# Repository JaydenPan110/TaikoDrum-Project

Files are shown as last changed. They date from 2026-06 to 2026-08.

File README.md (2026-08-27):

# Arduino Slot Machine

616CD408-CAEE-421D-8965-62FF21B37599_L0_001-2026-06-23, 9_50_43 AM

An interactive, hardware-driven slot machine featuring three physical reels, automated coin detection, a joystick lever mechanism, and a custom payout dispenser. 

---

## Project Overview

This project is a physical, interactive slot machine powered by dual Arduino microcontrollers. The system replicates a classic casino game loop using automated mechanical and electronic components:

1. **Coin Insertion:** The user inserts a coin into the slot to arm the machine.
2. **The Spin:** Pulling the joystick down triggers three independent reels to spin. 
3. **The Stop:** Each motor sequentially self-adjusts to display a specific symbol to the user.
4. **The Payout:** If all three wheels align on the same symbol, a jackpot is triggered, activating a specialized servo-driven dispensing mechanism for a physical payout.

---

## Component List

| Category | Item | Quantity |
| :--- | :--- | :--- |
| **Microcontrollers & Shields** | Arduino UNO | 2 |
| | CNC Shield | 1 |
| **Actuators & Motors** | Nema 17 Stepper Motor | 3 |
| | Servo Motor | 1 |
| **Sensors & Inputs** | Analog Joystick | 1 |
| | Photoresistor (LDR) | 1 |
| | Infrared (IR) Receiver | 1 |
| | Infrared (IR) Remote | 1 |
| **Display & Audio** | Freenove 8 RGB LED Ring | 1 |
| | RGB LED | 1 |
| | Passive Buzzer | 1 |
| **Power & Cabling** | 12V 5A AC to DC Power Converter | 1 |
| | USB Cable | 1 |
| | Jumper Wires (M/M & M/F) | Assortment |
| **Discrete Components** | Resistors (220Ω, 1kΩ, 10kΩ) | Various |
| **Hardware & Enclosure** | 3D Printed Components (Reels/Gears) | Custom |
| | M2.5 Screws and Nuts | 12 |
| | Wood Support Brackets & Housing | Custom |

## Schematic Pictures ( might be a bit outdated ) 




## Project Evolution & Changelog

The design of this slot machine evolved significantly during prototyping to adapt to structural requirements and improve user experience:

### Input Mechanism: From Push-Button to Joystick
* **Original Plan:** A simple arcade button to trigger the spin sequence after coin validation.
* **Revision:** Replaced the button and its status LED with an analog joystick. Pulling the joystick down provides a more tactile, satisfying "slot machine lever" feel.

### Coin Detection: From Optical Interruption to Contact Sensing
* **Original Plan:** A break-beam sensor configuration where a falling coin temporarily blocked an LED shining on a detector.
* **Revision:** Simplified to a direct-contact photoresistor setup inside the coin chute. Integrated a passive buzzer audio cue to sound a confirmation tone immediately upon reliable detection.

### Enclosure Design: From Cardboard to Reinforced Wood
* **Original Plan:** A fully 3D-printed enclosure or light cardboard housing.
* **Revision:** 3D printing the entire structural shell proved too time-consuming, while cardboard lacked the structural integrity to support the torque and weight of three Nema 17 stepper motors. The structural framing was redesigned using wood, successfully neutralizing motor vibrations and improving overall system durability.

credit to [WhiteStudio](https://makerworld.com/en/models/1272917-nanoslot-modular-arduino-based-slot-machine-w-rtp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) for CAD models

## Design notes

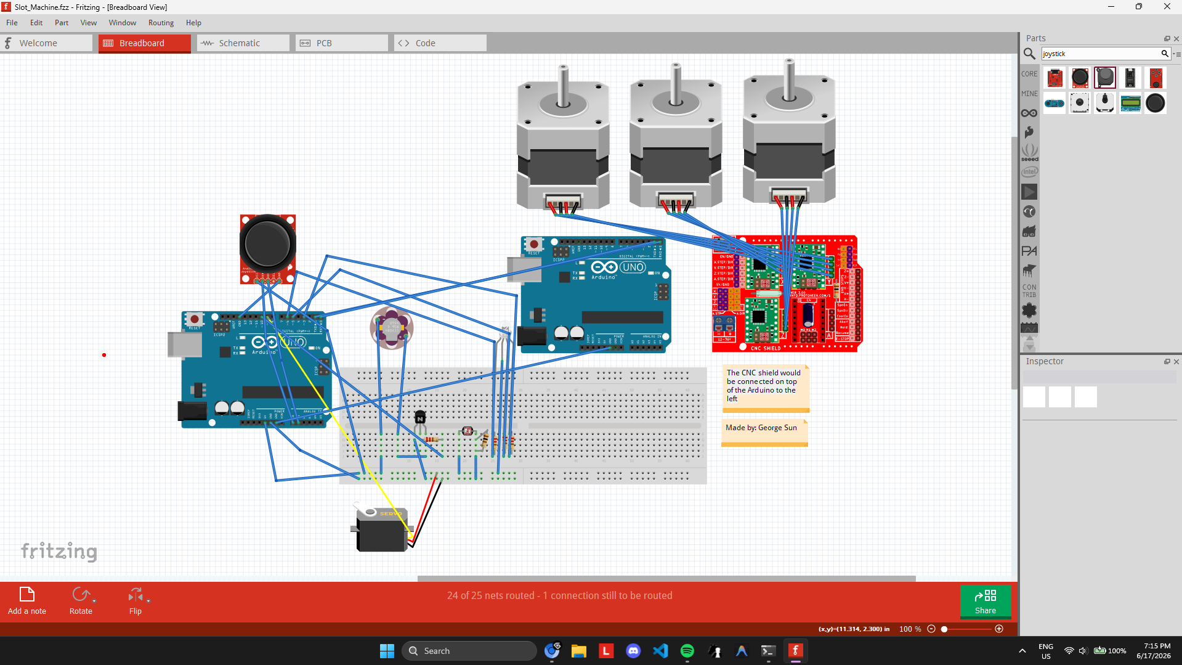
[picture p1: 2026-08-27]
PCB/Screenshot 2026-06-17 191529.png

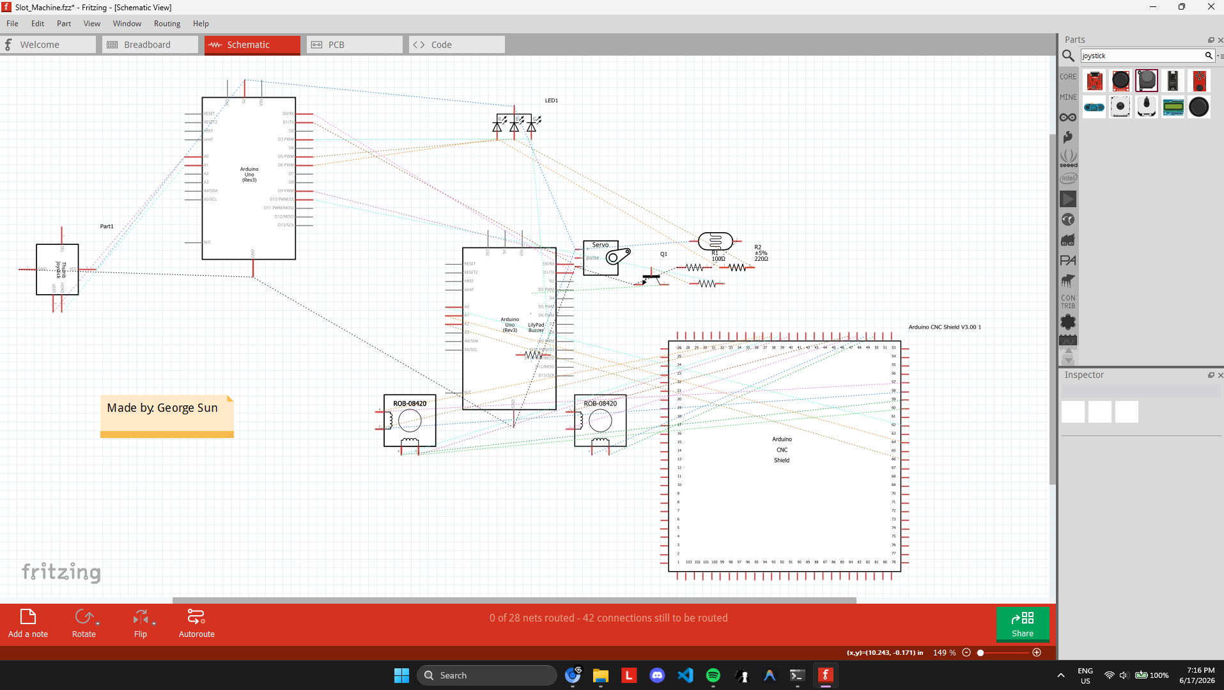
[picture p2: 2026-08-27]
PCB/Screenshot 2026-06-17 191656.png

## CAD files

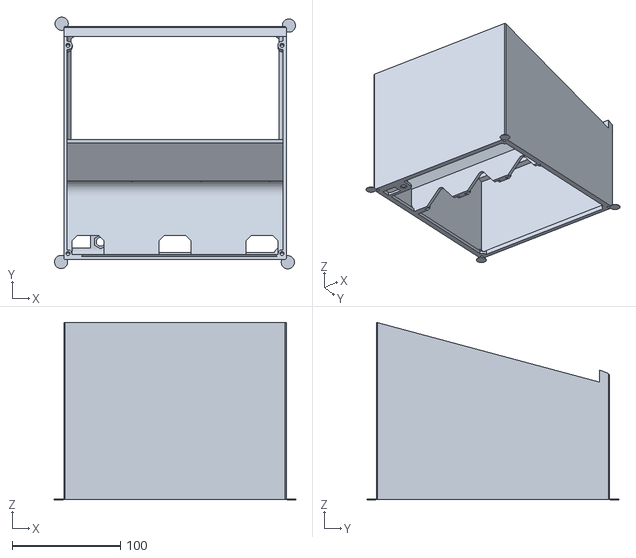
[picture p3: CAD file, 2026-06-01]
CAD/obj_8_Main body small.stl
222.7 x 232.6 x 163.9

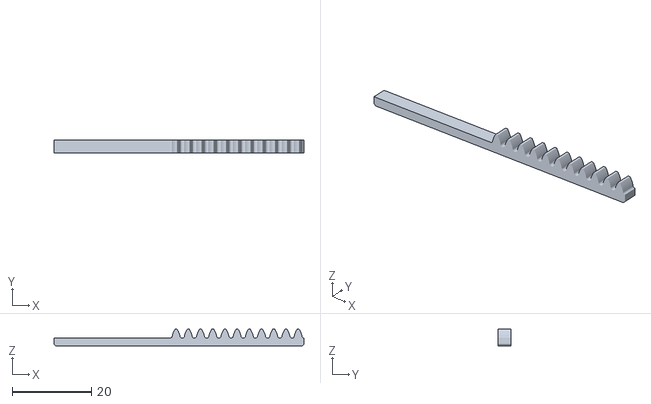
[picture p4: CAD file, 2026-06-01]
CAD/obj_6_Rack small.stl
63.0 x 3.23 x 4.17

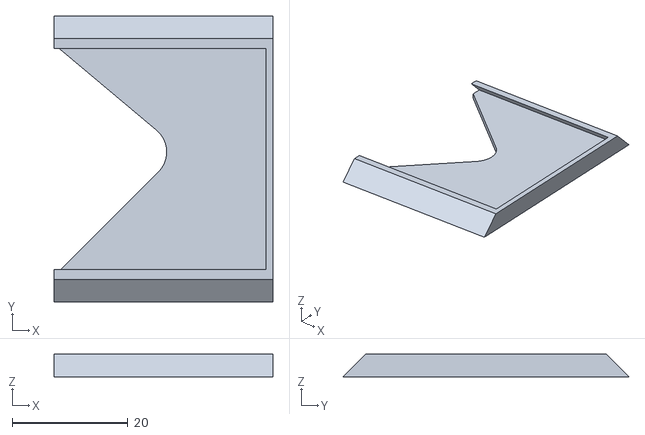
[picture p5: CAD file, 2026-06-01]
CAD/obj_7_Hold in place small.stl
37.7 x 49.4 x 3.92

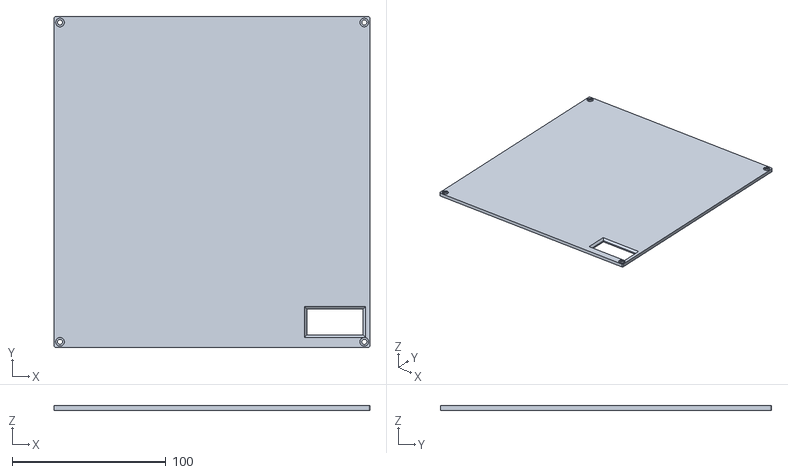
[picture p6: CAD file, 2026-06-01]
CAD/obj_3_Back plate small.stl
205.6 x 215.4 x 2.94

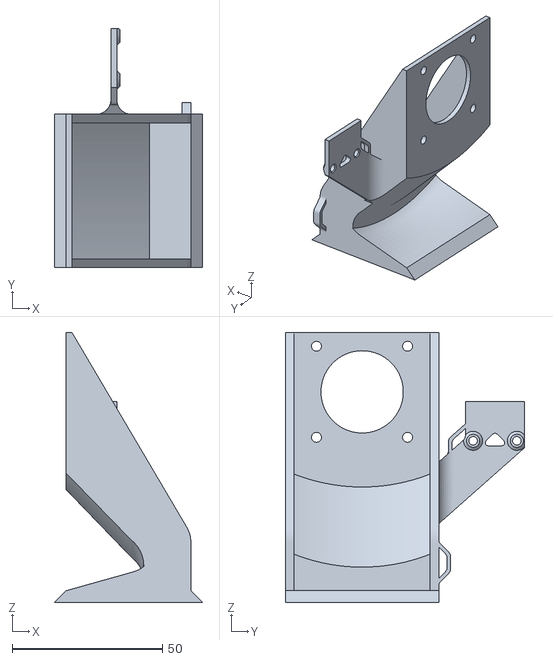
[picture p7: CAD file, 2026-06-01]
CAD/obj_1_Bracket new small.stl
49.4 x 79.7 x 89.9

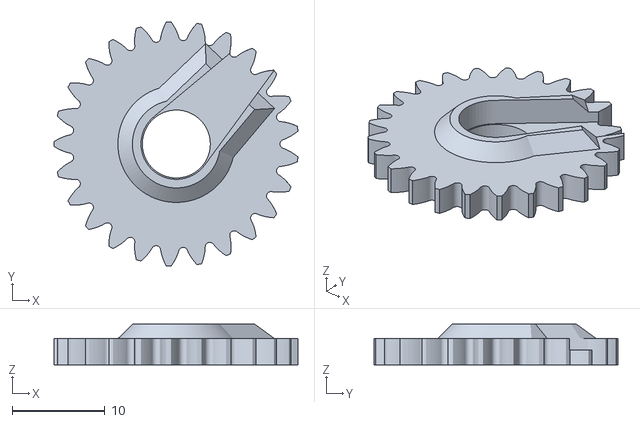
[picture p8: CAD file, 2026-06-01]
CAD/obj_4_Pinion small.stl
26.4 x 26.4 x 4.41

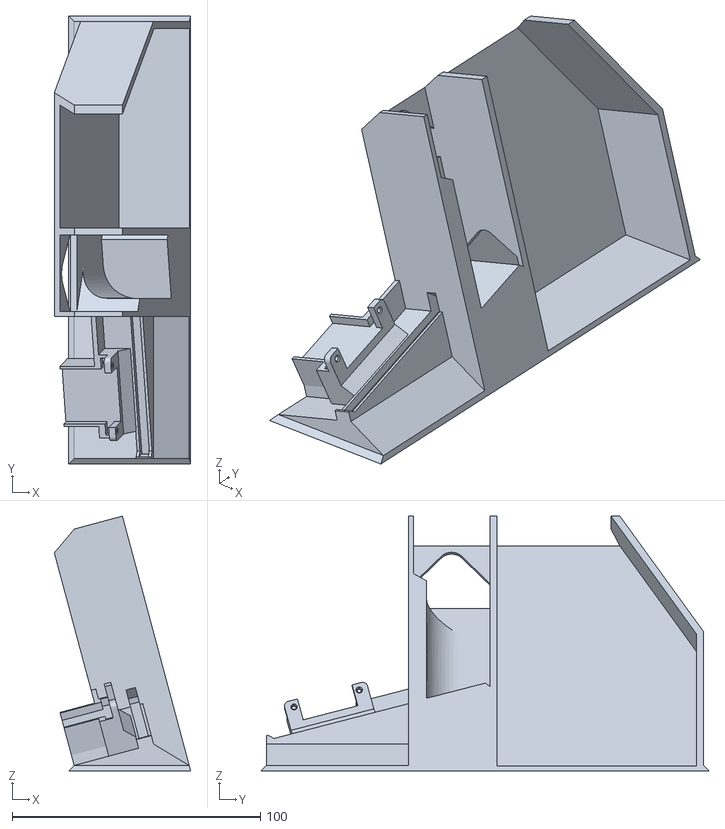
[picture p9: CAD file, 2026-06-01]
CAD/obj_2_Coin dispenser body small.stl
55.0 x 180.6 x 102.7

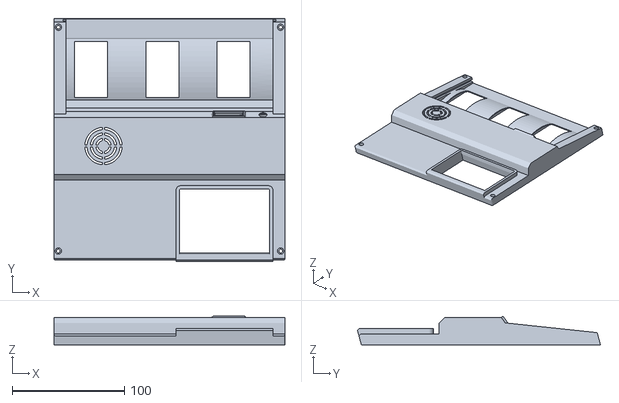
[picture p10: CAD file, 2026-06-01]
CAD/obj_9_cabinet front panel small.stl
205.6 x 216.3 x 25.6

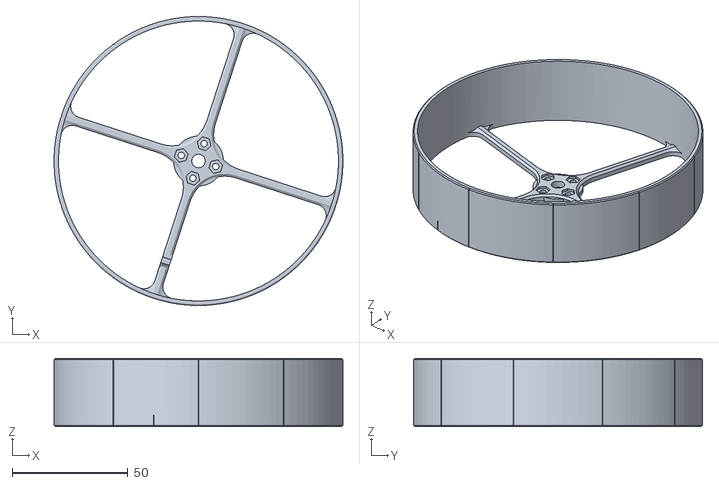
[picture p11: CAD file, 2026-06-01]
CAD/obj_5_Reel small.stl
124.6 x 124.6 x 29.4

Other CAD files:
CAD/obj_8_Main body.step
CAD/obj_3_Back plate.step
CAD/obj_2_Coin dispenser body.step
CAD/obj_6_Rack.step
CAD/obj_7_Hold in place.step
CAD/obj_1_Bracket new.step
CAD/obj_5_Reel.step
CAD/obj_4_Pinion.step
CAD/obj_9_cabinet front panel.step

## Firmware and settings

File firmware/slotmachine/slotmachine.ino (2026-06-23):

#include <pitches.h>
#include <Servo.h>
#include <IRremote.hpp>
#include <Adafruit_NeoPixel.h>
#include <AccelStepper.h>

enum Symbol {
  SYM_CHERRY,
  SYM_SEVEN,
  SYM_LIMON,
  SYM_BAR,
  SYM_MANDERIN,
  SYM_WATERMELON,
  SYM_BELL,
  SYM_BAR2,
  SYM_BANANA,
  SYM_GRAPE
};

const String SYMBOL_NAMES[] = {
  "CHERRY",
  "Seven",
  "LIMON",
  "BAR",
  "MANDERIN",
  "WATERMELON",
  "BELL",
  "BAR2",
  "BANANA",
  "GRAPE"
};

static const int PHYS_TO_LOG[10] = {6, 7, 8, 9, 0, 1, 2, 3, 4, 5};

int getSymbol(long position) {
  return PHYS_TO_LOG[((position + 80) % 200) / 20];
}

#define IR_RECEIVE_PIN 12
#define IR_PLAY_BUTTON 0xEA15FF00

#define LDR_PIN A0
#define BUZZER_PIN 10
#define BUTTON_PIN 2

#define LED_R 6
#define LED_G 5
#define LED_B 3

const int servoPin = 9;
#define NEO_PIN 11
#define NUM_LEDS 8

Adafruit_NeoPixel strip(NUM_LEDS, NEO_PIN, NEO_GRB + NEO_KHZ800);

#define STEP_X A2
#define STEP_Y A3
#define STEP_Z A4
#define DIR_PIN A5

#define SPIN_TARGET 50000

AccelStepper stepperX(AccelStepper::DRIVER, STEP_X, DIR_PIN);
AccelStepper stepperY(AccelStepper::DRIVER, STEP_Y, DIR_PIN);
AccelStepper stepperZ(AccelStepper::DRIVER, STEP_Z, DIR_PIN);

Servo coinServo;

int melody[] = {
  NOTE_E5, NOTE_E5, REST, NOTE_E5, REST, NOTE_C5, NOTE_E5,
  NOTE_G5, REST, NOTE_G4, REST, 
  NOTE_C5, NOTE_G4, REST, NOTE_E4,
  NOTE_A4, NOTE_B4, NOTE_AS4, NOTE_A4,
  NOTE_G4, NOTE_E5, NOTE_G5, NOTE_A5, NOTE_F5, NOTE_G5,
  REST, NOTE_E5,NOTE_C5, NOTE_D5, NOTE_B4,
  NOTE_C5, NOTE_G4, REST, NOTE_E4,
  NOTE_A4, NOTE_B4, NOTE_AS4, NOTE_A4,
  NOTE_G4, NOTE_E5, NOTE_G5, NOTE_A5, NOTE_F5, NOTE_G5,
  REST, NOTE_E5,NOTE_C5, NOTE_D5, NOTE_B4,
  
  REST, NOTE_G5, NOTE_FS5, NOTE_F5, NOTE_DS5, NOTE_E5,
  REST, NOTE_GS4, NOTE_A4, NOTE_C4, REST, NOTE_A4, NOTE_C5, NOTE_D5,
  REST, NOTE_DS5, REST, NOTE_D5,
  NOTE_C5, REST,
  
  REST, NOTE_G5, NOTE_FS5, NOTE_F5, NOTE_DS5, NOTE_E5,
  REST, NOTE_GS4, NOTE_A4, NOTE_C4, REST, NOTE_A4, NOTE_C5, NOTE_D5,
  REST, NOTE_DS5, REST, NOTE_D5,
  NOTE_C5, REST,
  
  NOTE_C5, NOTE_C5, NOTE_C5, REST, NOTE_C5, NOTE_D5,
  NOTE_E5, NOTE_C5, NOTE_A4, NOTE_G4,
  
  NOTE_C5, NOTE_C5, NOTE_C5, REST, NOTE_C5, NOTE_D5, NOTE_E5,
  REST, 
  NOTE_C5, NOTE_C5, NOTE_C5, REST, NOTE_C5, NOTE_D5,
  NOTE_E5, NOTE_C5, NOTE_A4, NOTE_G4,
  NOTE_E5, NOTE_E5, REST, NOTE_E5, REST, NOTE_C5, NOTE_E5,
  NOTE_G5, REST, NOTE_G4, REST, 
  NOTE_C5, NOTE_G4, REST, NOTE_E4,
  
  NOTE_A4, NOTE_B4, NOTE_AS4, NOTE_A4,
  NOTE_G4, NOTE_E5, NOTE_G5, NOTE_A5, NOTE_F5, NOTE_G5,
  REST, NOTE_E5, NOTE_C5, NOTE_D5, NOTE_B4,
  
  NOTE_C5, NOTE_G4, REST, NOTE_E4,
  NOTE_A4, NOTE_B4, NOTE_AS4, NOTE_A4,
  NOTE_G4, NOTE_E5, NOTE_G5, NOTE_A5, NOTE_F5, NOTE_G5,
  REST, NOTE_E5, NOTE_C5, NOTE_D5, NOTE_B4,
  
  NOTE_E5, NOTE_C5, NOTE_G4, REST, NOTE_GS4,
  NOTE_A4, NOTE_F5, NOTE_F5, NOTE_A4,
  NOTE_D5, NOTE_A5, NOTE_A5, NOTE_A5, NOTE_G5, NOTE_F5,
  
  NOTE_E5, NOTE_C5, NOTE_A4, NOTE_G4,
  NOTE_E5, NOTE_C5, NOTE_G4, REST, NOTE_GS4,
  NOTE_A4, NOTE_F5, NOTE_F5, NOTE_A4,
  NOTE_B4, NOTE_F5, NOTE_F5, NOTE_F5, NOTE_E5, NOTE_D5,
  NOTE_C5, NOTE_E4, NOTE_E4, NOTE_C4,
  
  NOTE_E5, NOTE_C5, NOTE_G4, REST, NOTE_GS4,
  NOTE_A4, NOTE_F5, NOTE_F5, NOTE_A4,
  NOTE_D5, NOTE_A5, NOTE_A5, NOTE_A5, NOTE_G5, NOTE_F5,
  
  NOTE_E5, NOTE_C5, NOTE_A4, NOTE_G4,
  NOTE_E5, NOTE_C5, NOTE_G4, REST, NOTE_GS4,
  NOTE_A4, NOTE_F5, NOTE_F5, NOTE_A4,
  NOTE_B4, NOTE_F5, NOTE_F5, NOTE_F5, NOTE_E5, NOTE_D5,
  NOTE_C5, NOTE_E4, NOTE_E4, NOTE_C4,
  NOTE_C5, NOTE_C5, NOTE_C5, REST, NOTE_C5, NOTE_D5, NOTE_E5,
  REST,
  
  NOTE_C5, NOTE_C5, NOTE_C5, REST, NOTE_C5, NOTE_D5,
  NOTE_E5, NOTE_C5, NOTE_A4, NOTE_G4,
  NOTE_E5, NOTE_E5, REST, NOTE_E5, REST, NOTE_C5, NOTE_E5,
  NOTE_G5, REST, NOTE_G4, REST, 
  NOTE_E5, NOTE_C5, NOTE_G4, REST, NOTE_GS4,
  NOTE_A4, NOTE_F5, NOTE_F5, NOTE_A4,
  NOTE_D5, NOTE_A5, NOTE_A5, NOTE_A5, NOTE_G5, NOTE_F5,
  
  NOTE_E5, NOTE_C5, NOTE_A4, NOTE_G4,
  NOTE_E5, NOTE_C5, NOTE_G4, REST, NOTE_GS4,
  NOTE_A4, NOTE_F5, NOTE_F5, NOTE_A4,
  NOTE_B4, NOTE_F5, NOTE_F5, NOTE_F5, NOTE_E5, NOTE_D5,
  NOTE_C5, NOTE_E4, NOTE_E4, NOTE_C4,
  
  // Game over sound
  NOTE_C5, NOTE_G4, NOTE_E4,
  NOTE_A4, NOTE_B4, NOTE_A4, NOTE_GS4, NOTE_AS4, NOTE_GS4,
  NOTE_G4, NOTE_D4, NOTE_E4
};

int durations[] = {
  8, 8, 8, 8, 8, 8, 8,
  4, 4, 8, 4, 
  4, 8, 4, 4,
  4, 4, 8, 4,
  8, 8, 8, 4, 8, 8,
  8, 4,8, 8, 4,
  4, 8, 4, 4,
  4, 4, 8, 4,
  8, 8, 8, 4, 8, 8,
  8, 4,8, 8, 4,
  
  
  4, 8, 8, 8, 4, 8,
  8, 8, 8, 8, 8, 8, 8, 8,
  4, 4, 8, 4,
  2, 2,
  
  4, 8, 8, 8, 4, 8,
  8, 8, 8, 8, 8, 8, 8, 8,
  4, 4, 8, 4,
  2, 2,
  
  8, 4, 8, 8, 8, 4,
  8, 4, 8, 2,
  
  8, 4, 8, 8, 8, 8, 8,
  1, 
  8, 4, 8, 8, 8, 4,
  8, 4, 8, 2,
  8, 8, 8, 8, 8, 8, 4,
  4, 4, 4, 4, 
  4, 8, 4, 4,
  
  4, 4, 8, 4,
  8, 8, 8, 4, 8, 8,
  8, 4, 8, 8, 4,
  
  4, 8, 4, 4,
  4, 4, 8, 4,
  8, 8, 8, 4, 8, 8,
  8, 4, 8, 8, 4,
  
  8, 4, 8, 4, 4,
  8, 4, 8, 2,
  8, 8, 8, 8, 8, 8,
  
  8, 4, 8, 2,
  8, 4, 8, 4, 4,
  8, 4, 8, 2,
  8, 4, 8, 8, 8, 8,
  8, 4, 8, 2,
  
  8, 4, 8, 4, 4,
  8, 4, 8, 2,
  8, 8, 8, 8, 8, 8,
  
  8, 4, 8, 2,
  8, 4, 8, 4, 4,
  8, 4, 8, 2,
  8, 4, 8, 8, 8, 8,
  8, 4, 8, 2,
  8, 4, 8, 8, 8, 8, 8,
  1,
  
  8, 4, 8, 8, 8, 4,
  8, 4, 8, 2,
  8, 8, 8, 8, 8, 8, 4,
  4, 4, 4, 4, 
  8, 4, 8, 4, 4,
  8, 4, 8, 2,
  8, 8, 8, 8, 8, 8,
  
  8, 4, 8, 2,
  8, 4, 8, 4, 4,
  8, 4, 8, 2,
  8, 4, 8, 8, 8, 8,
  8, 4, 8, 2,
  
  //game over sound
  4, 4, 4,
  8, 8, 8, 8, 8, 8,
  8, 8, 2
};

int coinMelody[] = {
  NOTE_C4, REST, NOTE_G4, REST, NOTE_AS4, NOTE_C5, NOTE_AS4, REST, NOTE_F4, NOTE_DS4, REST,
  NOTE_C4, REST, NOTE_G4, REST, NOTE_AS4, NOTE_C5, NOTE_AS4, REST, NOTE_F4, NOTE_DS4, REST,
  NOTE_C4, REST, NOTE_G4, REST, NOTE_AS4, NOTE_C5, NOTE_AS4, REST, NOTE_F4, NOTE_DS4, REST,

  NOTE_C4, REST, NOTE_E4, REST, NOTE_G4, NOTE_A4, NOTE_AS4,
  NOTE_C5, REST, NOTE_C5, REST, NOTE_AS4, REST, NOTE_A4, REST,
  NOTE_AS4, REST, NOTE_AS4, NOTE_C5, REST, NOTE_AS4, NOTE_A4, REST,
  REST,
  NOTE_C5, REST, NOTE_AS4, REST, NOTE_A4, REST, NOTE_AS4, REST, NOTE_E5,
  REST,

  NOTE_C5, REST, NOTE_C5, REST, NOTE_AS4, REST, NOTE_A4, REST,
  NOTE_AS4, REST, NOTE_AS4, NOTE_C5, REST, NOTE_AS4, NOTE_A4, REST,
  REST,
  NOTE_C5, REST, NOTE_AS4, REST, NOTE_A4, REST, NOTE_AS4, REST, NOTE_E4,
  REST,
};

int coinDurations[] = {
  4, 8, 4, 8, 4, 8, 8, 16, 8, 8, 16,
  4, 8, 4, 8, 4, 8, 8, 16, 8, 8, 16,
  4, 8, 4, 8, 4, 8, 8, 16, 8, 8, 16,

  4, 8, 4, 8, 4, 4, 4,
  8, 16, 8, 16, 8, 16, 8, 16,
  8, 16, 8, 8, 16, 8, 8, 16,
  4,
  8, 16, 8, 16, 8, 16, 8, 4, 8,
  4,

  8, 16, 8, 16, 8, 16, 8, 16,
  8, 16, 8, 8, 16, 8, 8, 16,
  4,
  8, 16, 8, 16, 8, 16, 8, 4, 8,
  1
};

int spinMelody[] = {
  NOTE_E5, NOTE_B4, NOTE_C5, NOTE_D5, NOTE_C5, NOTE_B4,
  NOTE_A4, NOTE_A4, NOTE_C5, NOTE_E5, NOTE_D5, NOTE_C5,
  NOTE_B4, NOTE_C5, NOTE_D5, NOTE_E5,
  NOTE_C5, NOTE_A4, NOTE_A4, NOTE_A4, NOTE_B4, NOTE_C5,

  NOTE_D5, NOTE_F5, NOTE_A5, NOTE_G5, NOTE_F5,
  NOTE_E5, NOTE_C5, NOTE_E5, NOTE_D5, NOTE_C5,
  NOTE_B4, NOTE_B4, NOTE_C5, NOTE_D5, NOTE_E5,
  NOTE_C5, NOTE_A4, NOTE_A4, REST,

  NOTE_E5, NOTE_B4, NOTE_C5, NOTE_D5, NOTE_C5, NOTE_B4,
  NOTE_A4, NOTE_A4, NOTE_C5, NOTE_E5, NOTE_D5, NOTE_C5,
  NOTE_B4, NOTE_C5, NOTE_D5, NOTE_E5,
  NOTE_C5, NOTE_A4, NOTE_A4, NOTE_A4, NOTE_B4, NOTE_C5,

  NOTE_D5, NOTE_F5, NOTE_A5, NOTE_G5, NOTE_F5,
  NOTE_E5, NOTE_C5, NOTE_E5, NOTE_D5, NOTE_C5,
  NOTE_B4, NOTE_B4, NOTE_C5, NOTE_D5, NOTE_E5,
  NOTE_C5, NOTE_A4, NOTE_A4, REST,

  NOTE_E5, NOTE_C5,
  NOTE_D5, NOTE_B4,
  NOTE_C5, NOTE_A4,
  NOTE_GS4, NOTE_B4, REST,
  NOTE_E5, NOTE_C5,
  NOTE_D5, NOTE_B4,
  NOTE_C5, NOTE_E5, NOTE_A5,
  NOTE_GS5
};

int spinDurations[] = {
  4, 8, 8, 4, 8, 8,
  4, 8, 8, 4, 8, 8,
  4, 8, 4, 4,
  4, 4, 8, 4, 8, 8,

  4, 8, 4, 8, 8,
  4, 8, 4, 8, 8,
  4, 8, 8, 4, 4,
  4, 4, 4, 4,

  4, 8, 8, 4, 8, 8,
  4, 8, 8, 4, 8, 8,
  4, 8, 4, 4,
  4, 4, 8, 4, 8, 8,

  4, 8, 4, 8, 8,
  4, 8, 4, 8, 8,
  4, 8, 8, 4, 4,
  4, 4, 4, 4,

  2, 2,
  2, 2,
  2, 2,
  2, 4, 8,
  2, 2,
  2, 2,
  4, 4, 2,
  2
};

// Non-blocking state for buzzer
int currentNote = 0;
unsigned long noteTimer = 0;
int noteDuration = 0;
bool waitingForNote = false;
bool playingCoinSong = false;
bool playingSpinSong = false;

// Non-blocking state for dispenser
int coinsToDispense = 0;
int dispenseStep = 0; // 0=idle, 1=open_step, 2=wait_fall, 3=close_step, 4=wait_next
unsigned long dispenseTimer = 0;
int servoCurrentAngle = 0;
#define SERVO_STEP_DELAY 15
#define SERVO_ANGLE_STEP 3

#define LDR_THRESHOLD 50
#define JOY_THRESHOLD 50

// Non-blocking state for LDR
unsigned long ldrTimer = 0;
int prevLdrValue = 0;
unsigned long ldrDebounceTimer = 0;
bool ldrCooldown = false;
bool coinDropped = false;
#define LDR_COOLDOWN_MS 200

// Non-blocking state for joystick
unsigned long joyTimer = 0;
int prevJoyY = 512;
unsigned long joyDebounceTimer = 0;
#define JOY_COOLDOWN_MS 300

// Button state
int lastButtonState = HIGH;
int buttonState = HIGH;
unsigned long lastDebounceTime = 0;
const unsigned long debounceDelay = 50;

// Rainbow LED state
unsigned long rainbowTimer = 0;
unsigned int hue = 0;

// Green breathing animation state
bool rainbowMode = true;
unsigned long greenFadeTimer = 0;
int greenFadeLevel = 0;
bool greenFadeRising = true;

int breathR = 255;
int breathG = 0;
int breathB = 255;
bool spinning = false;
int spinPhase = 0;

unsigned long neoPrev = 0;
unsigned int neoHue = 0;

void setColor(int r, int g, int b)
{
  analogWrite(LED_R, 255 - r);
  analogWrite(LED_G, 255 - g);
  analogWrite(LED_B, 255 - b);
}

void hsvToRgb(unsigned int h, byte &r, byte &g, byte &b)
{
  unsigned int sector = h / 60;
  unsigned int remainder = h % 60;
  unsigned int ramp = (remainder * 255) / 60;

  byte low = 0;
  byte high = 255;

  switch (sector) {
    case 0: r = high; g = ramp; b = low; break;
    case 1: r = high - ramp; g = high; b = low; break;
    case 2: r = low; g = high; b = ramp; break;
    case 3: r = low; g = high - ramp; b = high; break;
    case 4: r = ramp; g = low; b = high; break;
    case 5: r = high; g = low; b = high - ramp; break;
  }
}

void runSteppers() {
  if (!spinning) return;

  stepperX.run();
  stepperY.run();
  stepperZ.run();

  if (spinPhase == 4 && stepperX.distanceToGo() == 0 && stepperY.distanceToGo() == 0 && stepperZ.distanceToGo() == 0) {
    spinning = false;
    playingSpinSong = false;
    spinPhase = 0;
    coinDropped = false;

    int xSym = getSymbol(stepperX.currentPosition());
    int ySym = getSymbol(stepperY.currentPosition());
    int zSym = getSymbol(stepperZ.currentPosition());
    Serial.print("Symbols: ");
    Serial.print(SYMBOL_NAMES[xSym]);
    Serial.print(" ");
    Serial.print(SYMBOL_NAMES[ySym]);
    Serial.print(" ");
    Serial.println(SYMBOL_NAMES[zSym]);

    if (xSym == ySym && ySym == zSym && dispenseStep == 0) {
      coinsToDispense = 3;
      dispenseStep = 1;
      dispenseTimer = millis();
    }

    rainbowMode = true;
    rainbowTimer = millis();
  }
}

void neoRainbow() {
  for (int i = 0; i < NUM_LEDS; i++) {
    int hue = (neoHue + i * 45) % 360;
    byte r, g, b;
    hsvToRgb(hue, r, g, b);
    strip.setPixelColor(i, r, g, b);
  }
  strip.show();
}

void setup()
{
  Serial.begin(9600);
  IrReceiver.begin(IR_RECEIVE_PIN, DISABLE_LED_FEEDBACK);

  pinMode(BUZZER_PIN, OUTPUT);
  pinMode(BUTTON_PIN, INPUT);
  pinMode(LED_R, OUTPUT);
  pinMode(LED_G, OUTPUT);
  pinMode(LED_B, OUTPUT);

  coinServo.attach(servoPin);
  coinServo.write(0);
  servoCurrentAngle = 0;

  coinsToDispense = 0;
  dispenseStep = 0;

  strip.begin();
  strip.show();

  stepperX.setMaxSpeed(100.0);
  stepperX.setAcceleration(100.0);

  stepperY.setMaxSpeed(100.0);
  stepperY.setAcceleration(100.0);

  stepperZ.setMaxSpeed(100.0);
  stepperZ.setAcceleration(100.0);
}

void loop()
{
  int size = sizeof(durations) / sizeof(int);

  // --- LED (non-blocking) ---
  if (spinning) {
    if (millis() - greenFadeTimer >= 20) {
      greenFadeTimer = millis();
      if (greenFadeRising) {
        greenFadeLevel += 5;
        if (greenFadeLevel >= 255) {
          greenFadeLevel = 255;
          greenFadeRising = false;
        }
      } else {
        greenFadeLevel -= 5;
        if (greenFadeLevel <= 0) {
          greenFadeLevel = 0;
          greenFadeRising = true;
        }
      }
      setColor(
        (breathR * greenFadeLevel) / 255,
        (breathG * greenFadeLevel) / 255,
        (breathB * greenFadeLevel) / 255
      );
    }
  } else if (rainbowMode) {
    if (millis() - rainbowTimer >= 20) {
      rainbowTimer = millis();
      byte r, g, b;
      hsvToRgb(hue, r, g, b);
      setColor(r, g, b);
      hue = (hue + 1) % 360;
    }
  } else {
    if (millis() - greenFadeTimer >= 20) {
      greenFadeTimer = millis();
      if (greenFadeRising) {
        greenFadeLevel += 5;
        if (greenFadeLevel >= 255) {
          greenFadeLevel = 255;
          greenFadeRising = false;
        }
      } else {
        greenFadeLevel -= 5;
        if (greenFadeLevel <= 0) {
          greenFadeLevel = 0;
          greenFadeRising = true;
        }
      }
      setColor(
        (breathR * greenFadeLevel) / 255,
        (breathG * greenFadeLevel) / 255,
        (breathB * greenFadeLevel) / 255
      );
    }
  }

  // --- Stepper motors (non-blocking) ---
  runSteppers();

  // --- IR Remote (non-blocking) ---
  if (IrReceiver.decode()) {
    if (IrReceiver.decodedIRData.decodedRawData == IR_PLAY_BUTTON && !coinDropped) {
      coinDropped = true;
      playingCoinSong = true;
      currentNote = 0;
      waitingForNote = false;
      breathR = 0;
      breathG = 255;
      breathB = 0;
      greenFadeLevel = 0;
      greenFadeRising = true;
      greenFadeTimer = millis();
      if (rainbowMode) {
        rainbowMode = false;
        greenFadeLevel = 0;
        greenFadeRising = true;
        greenFadeTimer = millis();
      }
    }
    if (dispenseStep == 0) {
      int cmd = IrReceiver.decodedIRData.command;
      int coins = 0;
      if (cmd == 12) coins = 1;
      else if (cmd == 24) coins = 2;
      else if (cmd == 94) coins = 3;
      else if (cmd == 8) coins = 4;
      else if (cmd == 28) coins = 5;
      else if (cmd == 90) coins = 6;
      else if (cmd == 66) coins = 7;
      else if (cmd == 82) coins = 8;
      else if (cmd == 74) coins = 9;
      if (coins > 0) {
        coinsToDispense = coins;
        dispenseStep = 1;
        dispenseTimer = millis();
      }
    }
    IrReceiver.resume();
  }

  // --- NeoPixel Rainbow (non-blocking) ---
  if (millis() - neoPrev >= 30) {
    neoPrev = millis();
    neoRainbow();
    neoHue = (neoHue + 5) % 360;
  }

  // --- Buzzer (non-blocking) ---
  if (playingCoinSong) {
    int coinSize = sizeof(coinDurations) / sizeof(int);
    if (!waitingForNote) {
      noTone(BUZZER_PIN);
      noteDuration = 1000 / coinDurations[currentNote];
      if (coinMelody[currentNote] != REST) tone(BUZZER_PIN, coinMelody[currentNote], noteDuration);
      noteTimer = millis();
      waitingForNote = true;
    } else {
      int pause = noteDuration * 1.10;
      if (millis() - noteTimer >= pause) {
        currentNote = (currentNote + 1) % coinSize;
        noTone(BUZZER_PIN);
        waitingForNote = false;
      }
    }
  } else if (playingSpinSong) {
    int spinSize = sizeof(spinDurations) / sizeof(int);
    if (!waitingForNote) {
      noTone(BUZZER_PIN);
      noteDuration = 1000 / spinDurations[currentNote];
      if (spinMelody[currentNote] != REST) tone(BUZZER_PIN, spinMelody[currentNote], noteDuration);
      noteTimer = millis();
      waitingForNote = true;
    } else {
      int pause = noteDuration * 1.10;
      if (millis() - noteTimer >= pause) {
        currentNote = (currentNote + 1) % spinSize;
        noTone(BUZZER_PIN);
        waitingForNote = false;
      }
    }
  } else if (rainbowMode) {
    if (!waitingForNote) {
      noTone(BUZZER_PIN);
      noteDuration = 1000 / durations[currentNote];
      tone(BUZZER_PIN, melody[currentNote], noteDuration);
      noteTimer = millis();
      waitingForNote = true;
    } else {
      int pause = noteDuration * 1.10;
      if (millis() - noteTimer >= pause) {
        currentNote = (currentNote + 1) % size;
        noTone(BUZZER_PIN);
        waitingForNote = false;
      }
    }
  }

  // --- Button (non-blocking, debounced) ---
  int reading = digitalRead(BUTTON_PIN);
  if (reading != lastButtonState) {
    lastDebounceTime = millis();
    lastButtonState = reading;
  }
  if (millis() - lastDebounceTime >= debounceDelay) {
    if (lastButtonState == LOW && buttonState == HIGH) {
    }
    buttonState = lastButtonState;
  }

  // --- LDR (non-blocking, every 10ms) ---
  if (millis() - ldrTimer >= 10) {
    ldrTimer = millis();

    if (ldrCooldown && millis() - ldrDebounceTimer >= LDR_COOLDOWN_MS) {
      ldrCooldown = false;
    }

    bool calibrating = (millis() < 10000);

    if (calibrating) {
      prevLdrValue = analogRead(LDR_PIN);
    } else if (!ldrCooldown && !coinDropped) {
      int ldrValue = analogRead(LDR_PIN);
      int diff = ldrValue - prevLdrValue;
      if (diff < 0 && abs(diff) > LDR_THRESHOLD) {
        tone(BUZZER_PIN, 1000, 50);
        prevLdrValue = ldrValue;
        ldrCooldown = true;
        ldrDebounceTimer = millis();
        coinDropped = true;

        playingCoinSong = true;
        currentNote = 0;
        waitingForNote = false;
        breathR = 0;
        breathG = 255;
        breathB = 0;
        greenFadeLevel = 0;
        greenFadeRising = true;
        greenFadeTimer = millis();

        if (rainbowMode) {
          rainbowMode = false;
          greenFadeLevel = 0;
          greenFadeRising = true;
          greenFadeTimer = millis();
        }
      } else if (diff > 0 && abs(diff) > LDR_THRESHOLD) {
        prevLdrValue = ldrValue;
      }
    }
  }

  // --- Joystick Y-axis (non-blocking, every 20ms) ---
  if (millis() - joyTimer >= 20) {
    joyTimer = millis();
    int joyY = analogRead(A1);
    int diff = joyY - prevJoyY;
    if (abs(diff) > 3) {
      prevJoyY = joyY;
      if (diff < 0 && abs(diff) > JOY_THRESHOLD && millis() - joyDebounceTimer >= JOY_COOLDOWN_MS) {
        joyDebounceTimer = millis();
        ldrCooldown = true;
        ldrDebounceTimer = millis();
        if (spinning && spinPhase >= 1 && spinPhase <= 3) {
          if (spinPhase == 1) {
            stepperX.moveTo(((stepperX.currentPosition() / 20) + 1) * 20);
            spinPhase = 2;
          } else if (spinPhase == 2) {
            stepperY.moveTo(((stepperY.currentPosition() / 20) + 1) * 20);
            spinPhase = 3;
          } else if (spinPhase == 3) {
            long pos = stepperZ.currentPosition();
            long target = ((pos / 20) + 1) * 20;
            while (target - pos < 80) target += 20;
            stepperZ.moveTo(target);
            spinPhase = 4;
          }
        } else if (coinDropped) {
          playingCoinSong = false;
          playingSpinSong = true;
          currentNote = 0;
          waitingForNote = false;
          spinning = true;
          spinPhase = 1;
          stepperX.moveTo(stepperX.currentPosition() + SPIN_TARGET);
          stepperY.moveTo(stepperY.currentPosition() + SPIN_TARGET);
          stepperZ.moveTo(stepperZ.currentPosition() + SPIN_TARGET);
          breathR = 255;
          breathG = 0;
          breathB = 0;
          greenFadeLevel = 0;
          greenFadeRising = true;
          greenFadeTimer = millis();
        } else {
          if (!rainbowMode) {
            breathR = 0;
            breathG = 255;
            breathB = 255;
          }
        }
      }
    }
  }

  // --- Dispenser (non-blocking) ---
  if (coinsToDispense > 0) {
    switch (dispenseStep) {
      case 1: // Gradually open
        if (millis() - dispenseTimer >= SERVO_STEP_DELAY) {
          servoCurrentAngle += SERVO_ANGLE_STEP;
          if (servoCurrentAngle >= 125) {
            servoCurrentAngle = 125;
            coinServo.write(servoCurrentAngle);
            dispenseTimer = millis();
            dispenseStep = 2;
          } else {
            coinServo.write(servoCurrentAngle);
            dispenseTimer = millis();
          }
        }
        break;
      case 2: // Wait at open for coin to fall
        if (millis() - dispenseTimer >= 1500) {
          dispenseTimer = millis();
          dispenseStep = 3;
        }
        break;
      case 3: // Gradually close
        if (millis() - dispenseTimer >= SERVO_STEP_DELAY) {
          servoCurrentAngle -= SERVO_ANGLE_STEP;
          if (servoCurrentAngle <= 0) {
            servoCurrentAngle = 0;
            coinServo.write(servoCurrentAngle);
            dispenseTimer = millis();
            dispenseStep = 4;
          } else {
            coinServo.write(servoCurrentAngle);
            dispenseTimer = millis();
          }
        }
        break;
      case 4: // Wait before next coin
        if (millis() - dispenseTimer >= 2000) {
          coinsToDispense--;
          if (coinsToDispense > 0) {
            dispenseStep = 1;
          } else {
            dispenseStep = 0;
          }
        }
        break;
    }
  }
}

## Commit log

2026-05-29 3d models
    [obj_1_Bracket new.stl, obj_2_Coin dispenser body.stl, obj_3_Back plate.stl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]
2026-06-17 add motor code
2026-07-03 Add schematic pictures to README
    Added schematic pictures to the README for better visualization.
2026-07-03 Enhance README with new image and title correction
    Updated the README to include a new image and corrected the section title for schematic pictures.
2026-08-27 organizing files
    [Slot_Machine.fzz, obj_1_Bracket new small.stl, obj_1_Bracket new.step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]
